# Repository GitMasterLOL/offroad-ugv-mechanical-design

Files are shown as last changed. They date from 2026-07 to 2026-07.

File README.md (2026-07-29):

# offroad-ugv-mechanical-design
My work as Mechatronics Intern at Vrishchik Technologies

---
## What this is

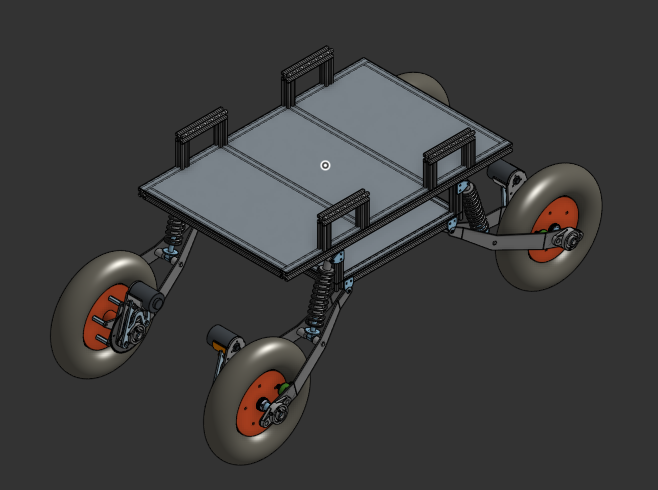
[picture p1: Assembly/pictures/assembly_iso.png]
assembly isometric view


This is a four wheeled trailing arm UGV designed for offroad logistics, developed at Vrishchik Technologies LLP. This repository is the **mechanical design report** containing CAD exports, renders, and drawings.

🔗 **[OnShape document link](https://cad.onshape.com/documents/ce47fbc74609b5a048dd3107/w/da249aea21ef6462a706381d/e/cdb04b3c972b51afe68cf9e2)**

---
## My role

As the Mechatronics Intern on this project, I worked on:
- Chassis load analysis, material selection, geometry analysis, design, structural analysis, and manufacturing 
- Trailing arm suspension kinematics, bearing selection, coilover sizing, design, and manufacturing
- Axle load case definition, stress analysis, material selection
- Evaluating chain drive sprocket mounting methods for manufacturability
- Chassis and mount design for onboard power and electronics

---
## Skills & tools demonstrated

- **CAD:** OnShape (parametric assemblies, dimensioned drawings for fabrication)
- **Suspension kinematics:** motion ratio calculation and tuning to hit a target wheel travel
- **Structural analysis:** stress and fatigue factor-of-safety calculation for axle sizing
- **DFM:** parts designed for minimal manufacturing complexity and cost
- **Manufacturing-aware design:** parts designed across 3D printing, CNC, laser cutting, and metal sheet bending

---
## Design highlights

**Chassis:** Aluminium T-Slot extrusions for weight management and rigidity (against bending and compression)

**Trailing arm suspension:** UCF205 pillow block bearings, ATV coilover shocks, ~200mm wheel travel

**Rear axle:** 304 stainless steel, fatigue FoS ≈ 2.4

---
## Repository map

```
TRAKR-rover/
├── README.md               ← you are here
├── Assembly/
│   ├── 3D_files/                Files of 3D printed components
│   ├── final_assembly.step              
│   ├── final_assembly.stl                
│   └── pictures/                 Pictures of assemblies and certain important components
└── drawings/                    dimensioned PDFs for anything fabricated
```

---
## Key specifications

| Parameter | Value |
|---|---|
| Overall dimensions (L×W×H) | 1m x 0.6m x 0.5m |
| Mass (as designed) | 100kg |
| Payload capacity | 100-120kg |
| Ground clearance | 300mm |
| Max traversable slope | 30 degrees |
| Wheel diameter | 14.5" |
| Primary materials | Aluminium, Mild steel |

---
## Fabrication

**Processes used:** 3D printing / CNC / laser cutting / sheet metal bending

**What has been completed:**
	- Chassis frame
	- First version of trailing arm suspension

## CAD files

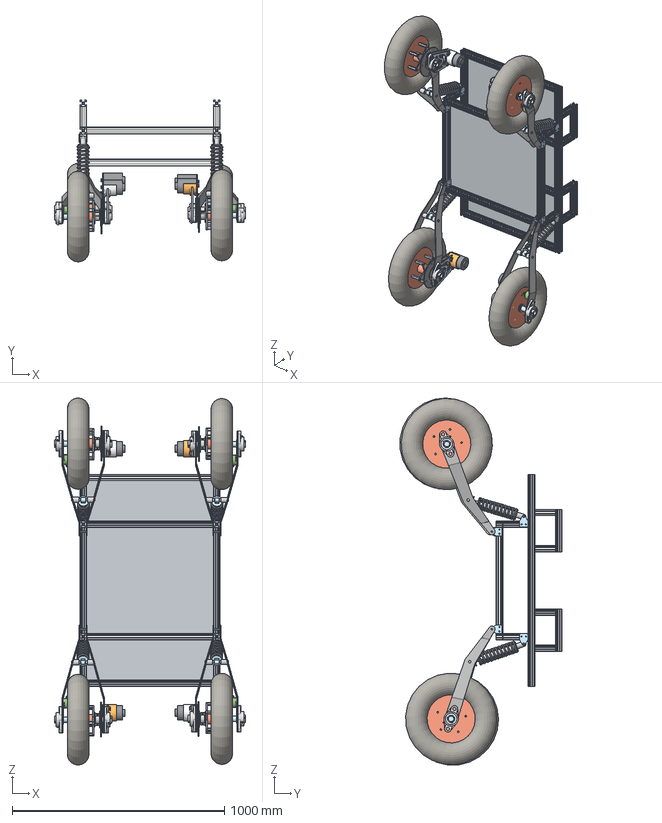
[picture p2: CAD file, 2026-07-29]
Assembly/final_assembly.step
902.4 x 763.2 x 1730.9 mm
shock pivot x 16
sheet x 2
mount x 4
GT2 60T x 4
motor x 4
trailing arm v2 left x 4
motor mount back plate x 4
shock to arm x 8
UCFL205J x 8
motor mount face plate x 4
trailing arm v2 right x 4
encoder x 4
motor mount base x 2
GT2 16T x 4
sprocket flange x 4
sprocket plate x 4
sprocket x 4
piston x 4
spring x 4
case x 4
spacer x 20
spider plate x 4
wheel x 4
spider collar 2 x 4
spider collar 1 x 4
rim x 4
motor mount base-Mirrored x 2

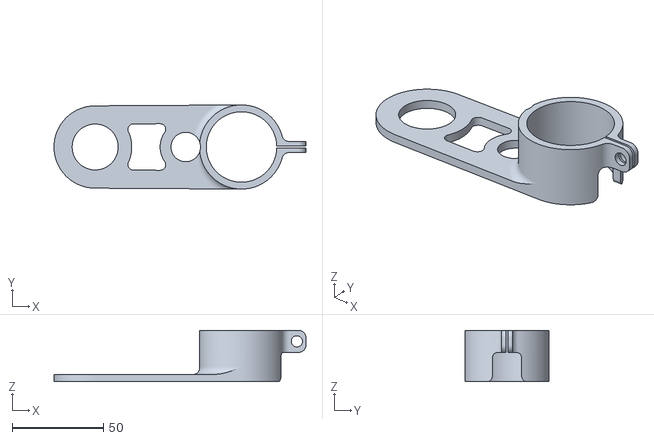
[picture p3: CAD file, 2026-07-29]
Assembly/3D_files/encoder mount.stl
137.7 x 46.0 x 28.0

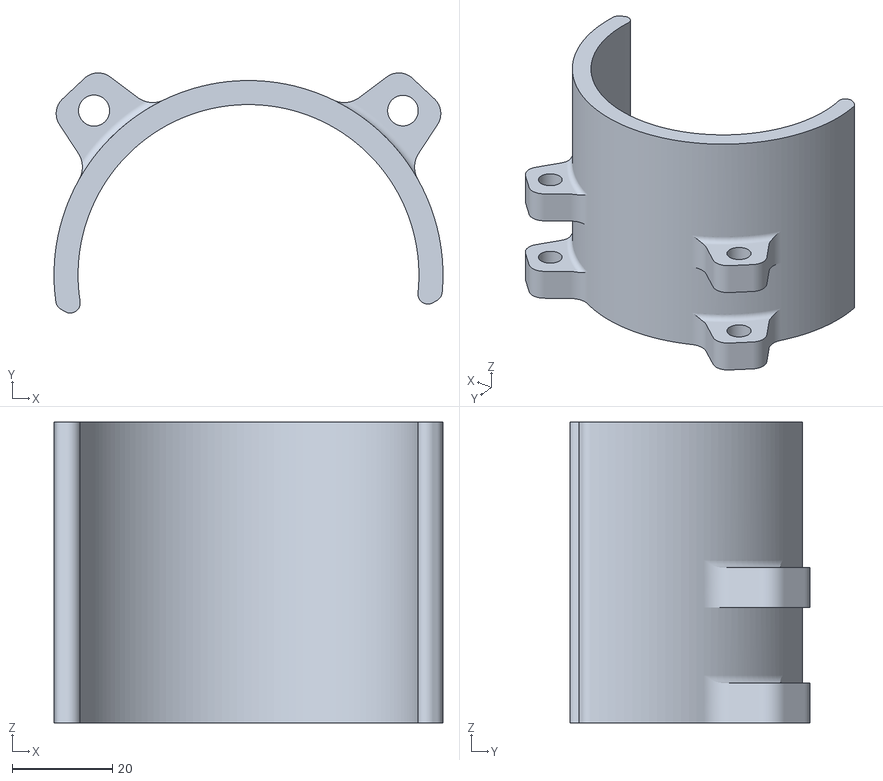
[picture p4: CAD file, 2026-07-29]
Assembly/3D_files/motor_mount/motor mount base.stl
77.6 x 47.9 x 60.0

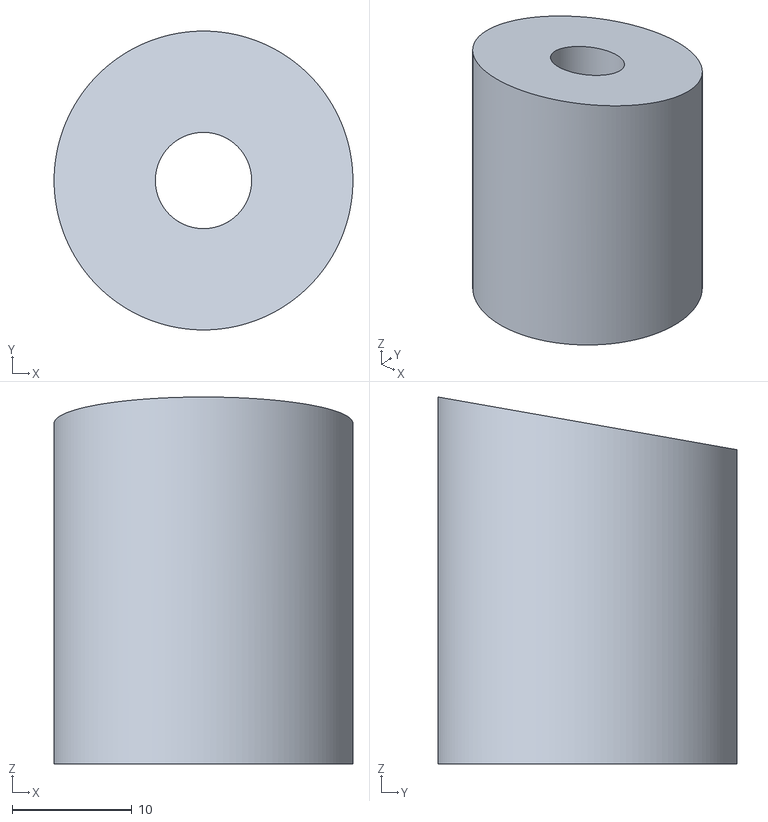
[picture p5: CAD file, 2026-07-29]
Assembly/3D_files/spacers/shock to arm v2.stl
25.0 x 25.0 x 30.7

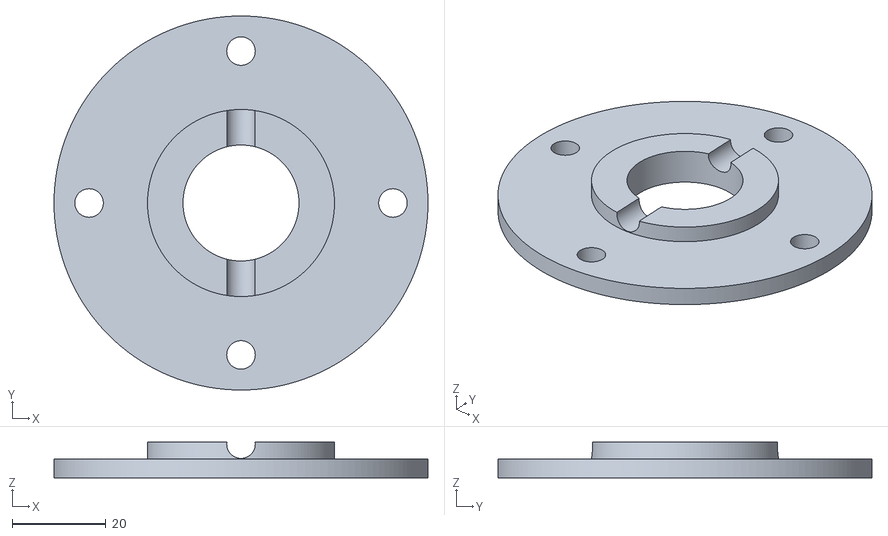
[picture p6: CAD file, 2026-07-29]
Assembly/3D_files/sprocket mount/sprocket mount - sprocket flange.stl
80.0 x 80.0 x 7.60

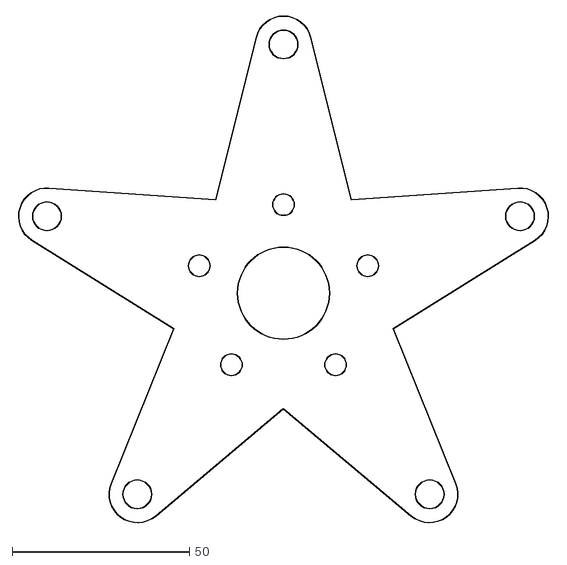
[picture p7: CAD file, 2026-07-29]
drawings/spider plate.dxf
151.1 x 143.7

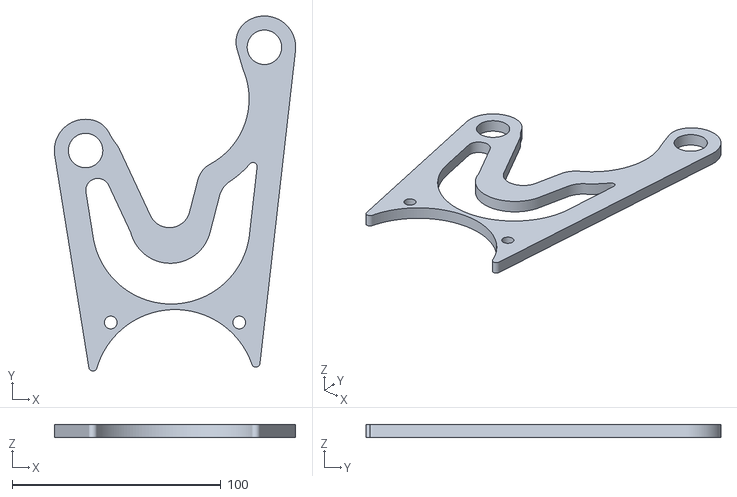
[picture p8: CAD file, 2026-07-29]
Assembly/3D_files/motor_mount/motor mount v2 - motor mount back plate.stl
115.7 x 170.2 x 6.00

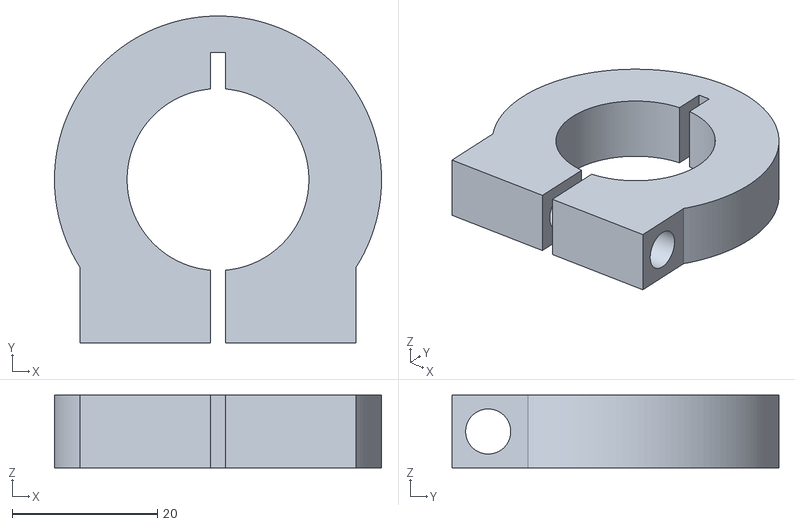
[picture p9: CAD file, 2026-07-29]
Assembly/3D_files/shaft_locker.stl
45.0 x 45.0 x 10.0

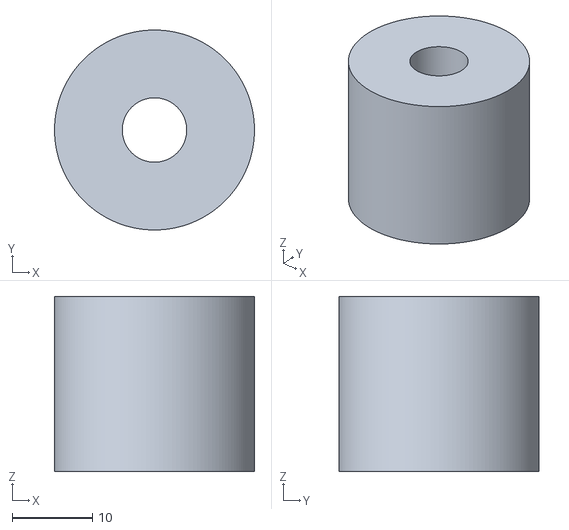
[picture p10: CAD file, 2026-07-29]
Assembly/3D_files/spacers/arm pivot.stl
25.0 x 25.0 x 21.9

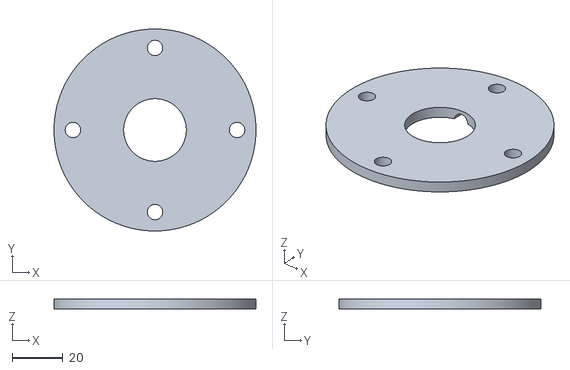
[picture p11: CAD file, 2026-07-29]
Assembly/3D_files/sprocket mount/sprocket mount - sprocket plate.stl
80.0 x 80.0 x 4.00

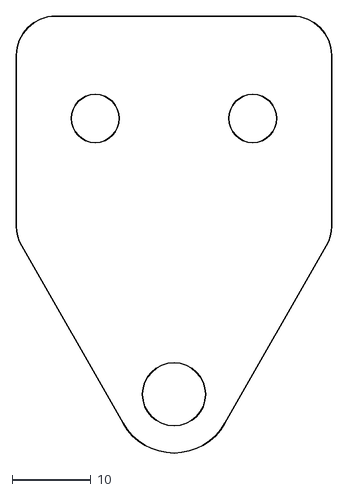
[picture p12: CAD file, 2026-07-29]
drawings/shock pivot.dxf
40.0 x 55.4

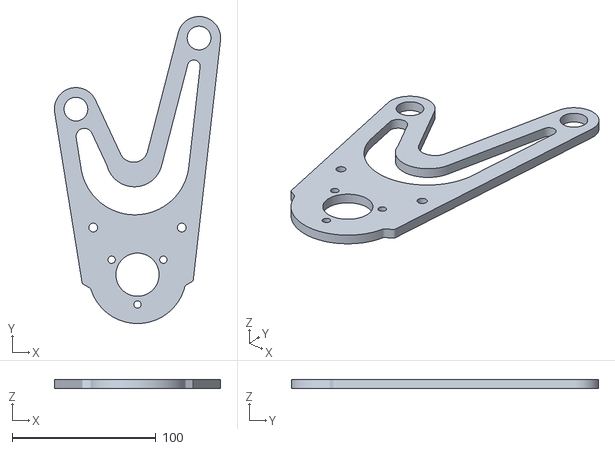
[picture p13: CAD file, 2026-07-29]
Assembly/3D_files/motor_mount/motor mount v2 - motor mount face plate.stl
115.7 x 213.7 x 6.00

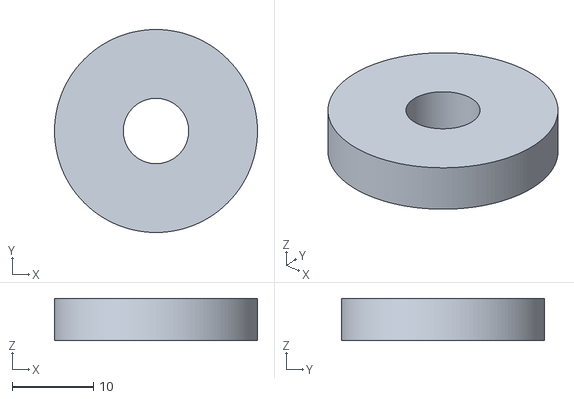
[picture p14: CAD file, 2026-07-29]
Assembly/3D_files/spacers/shock top v2.stl
25.0 x 25.0 x 5.20

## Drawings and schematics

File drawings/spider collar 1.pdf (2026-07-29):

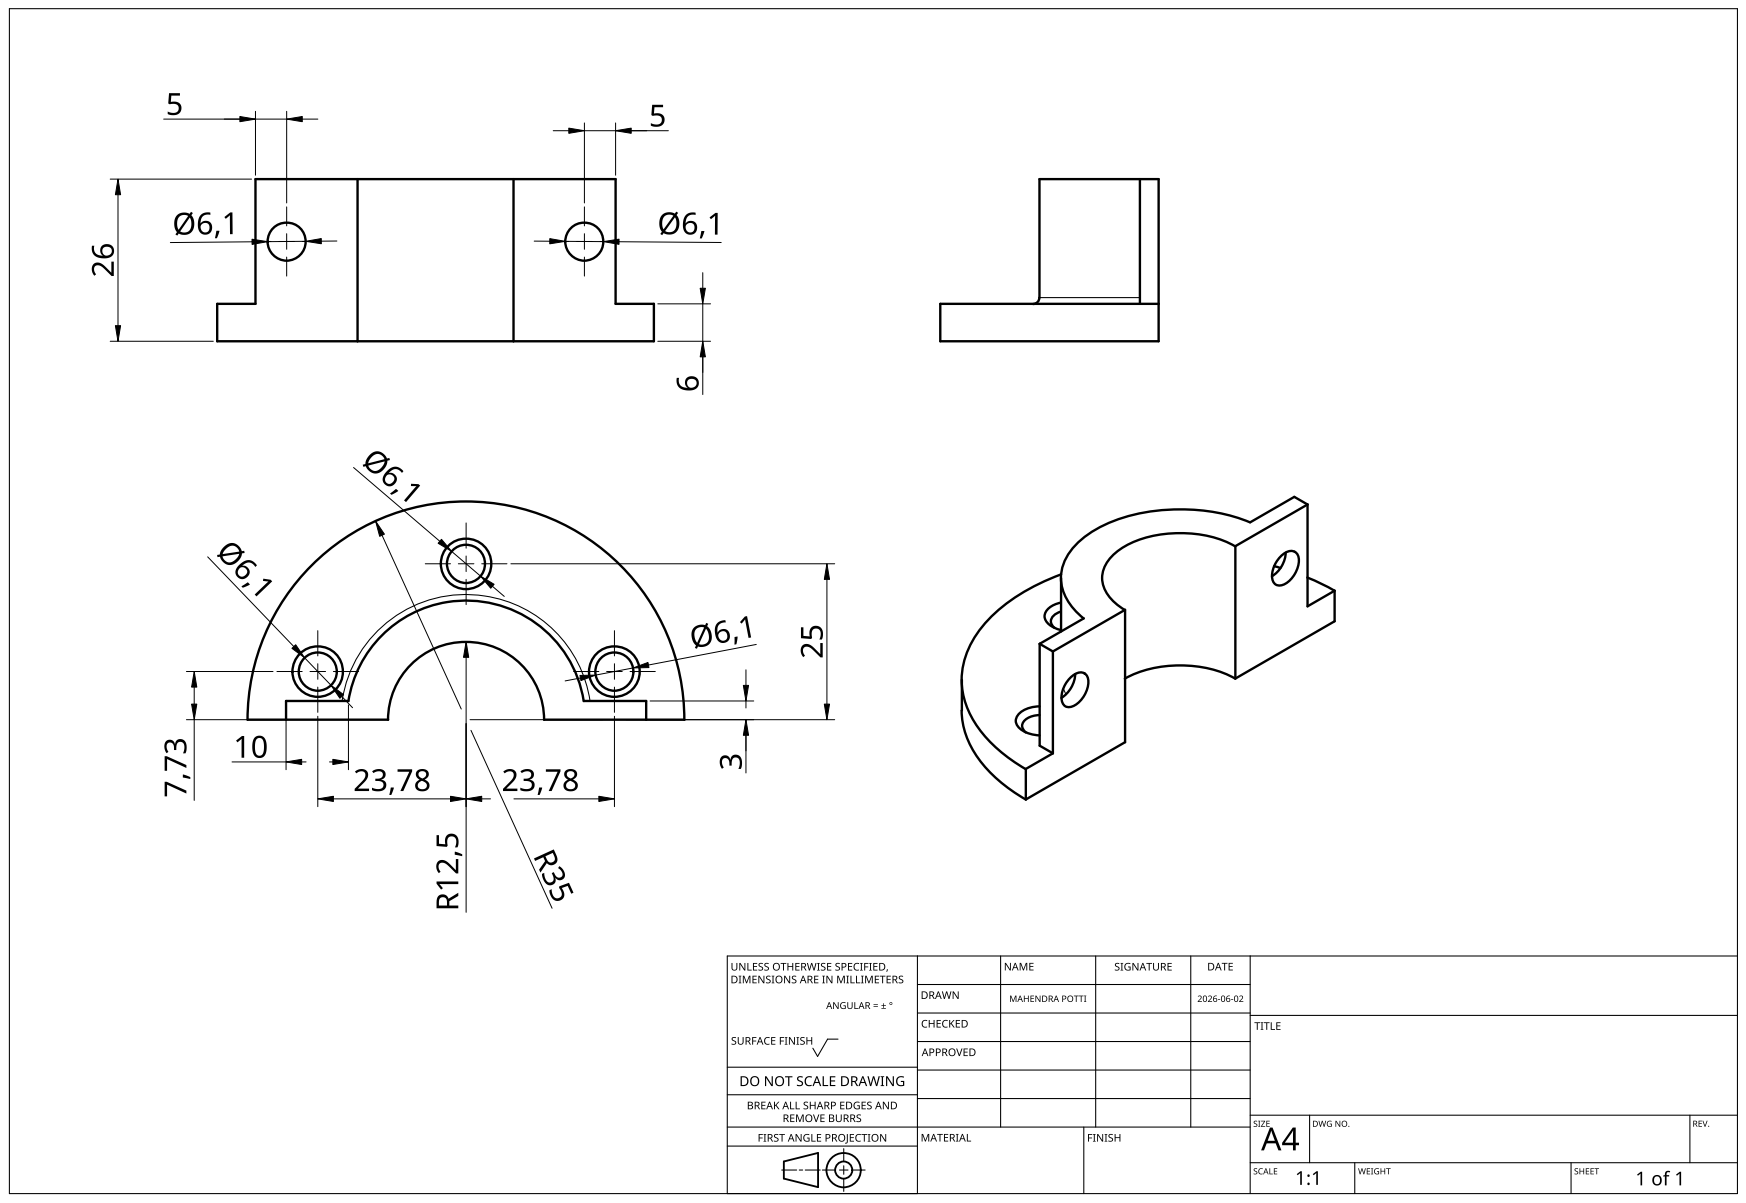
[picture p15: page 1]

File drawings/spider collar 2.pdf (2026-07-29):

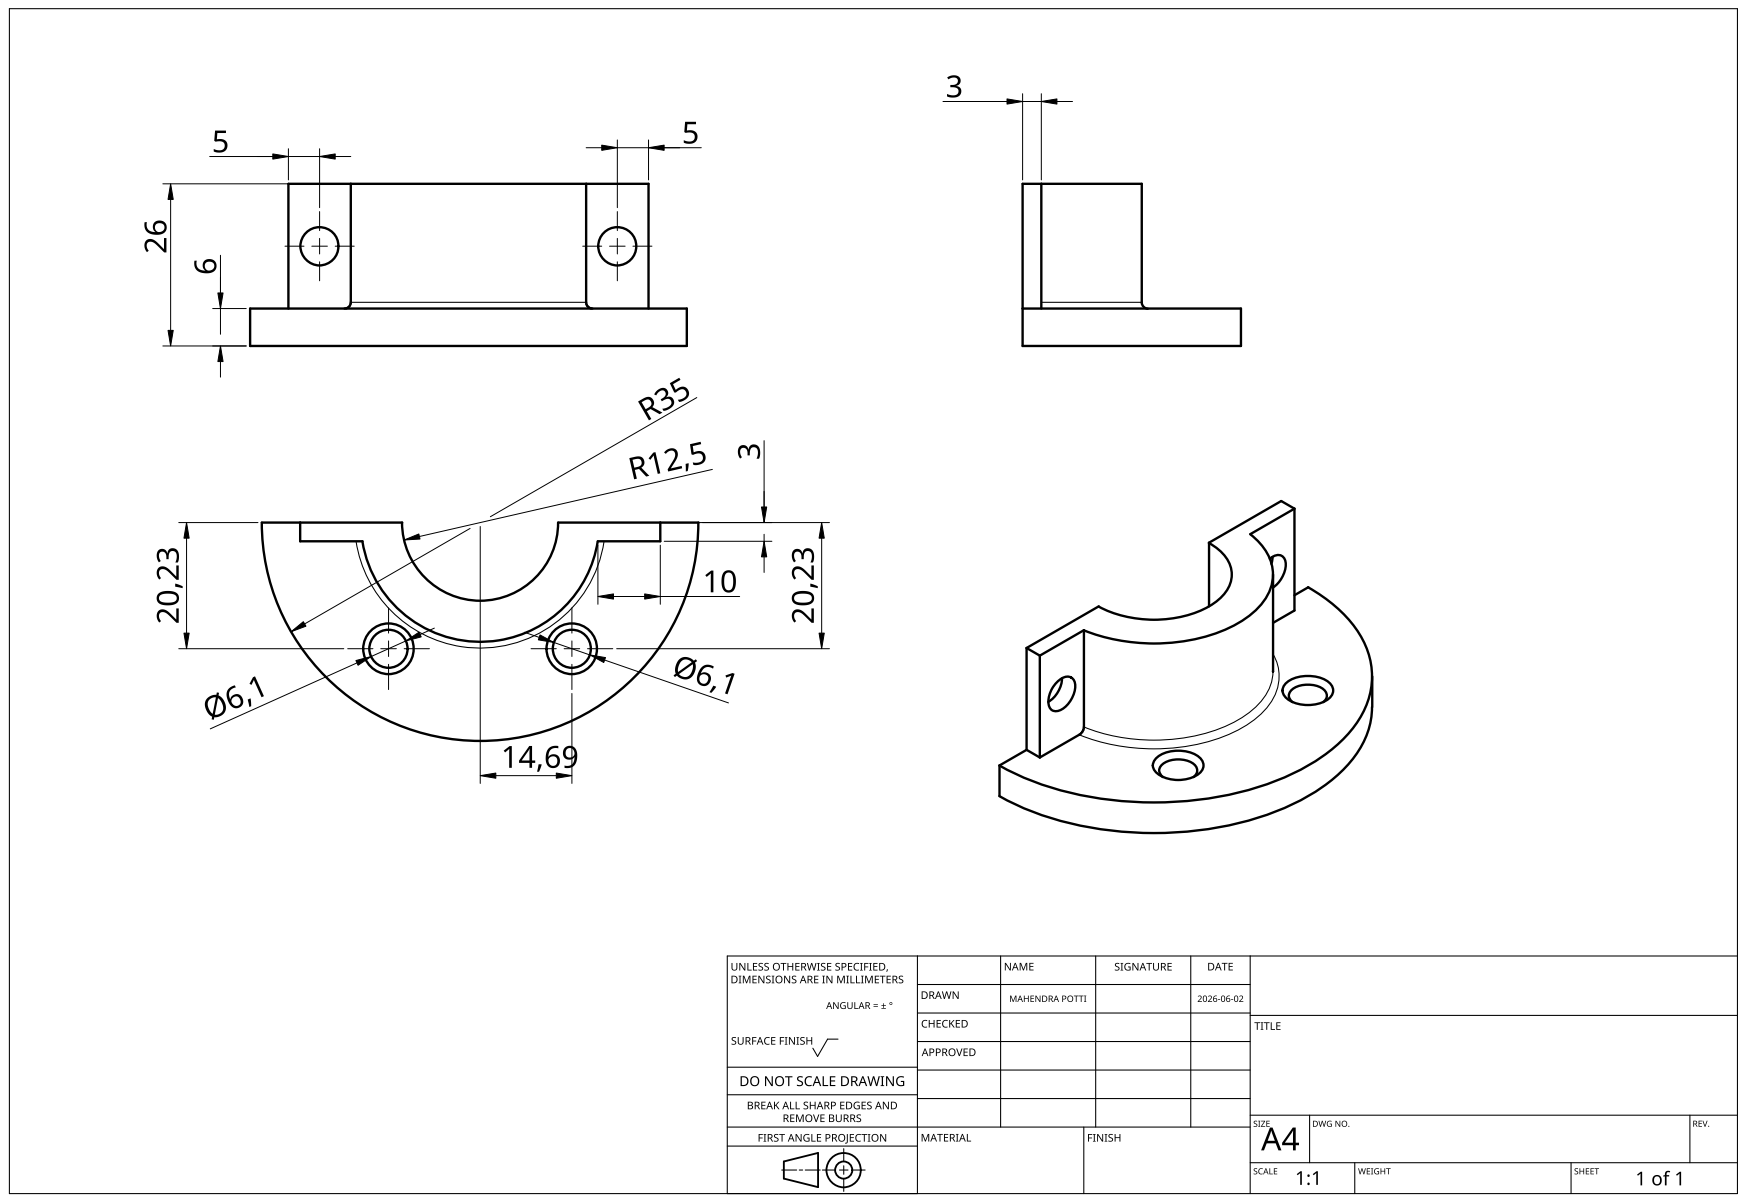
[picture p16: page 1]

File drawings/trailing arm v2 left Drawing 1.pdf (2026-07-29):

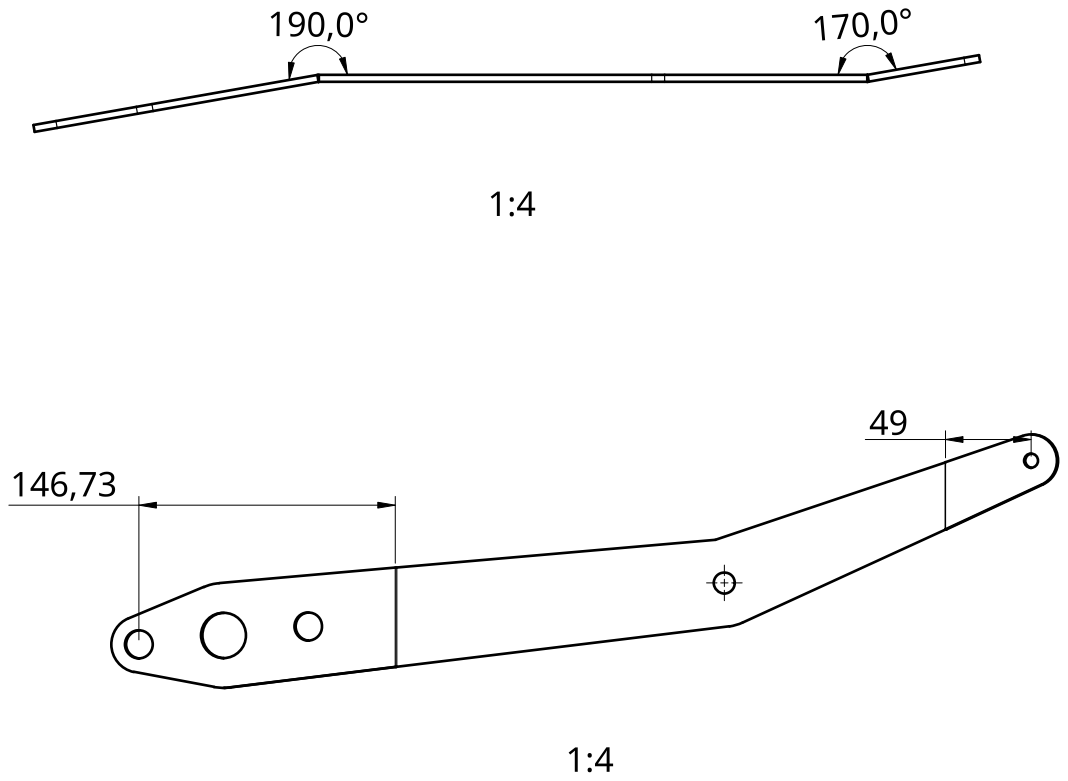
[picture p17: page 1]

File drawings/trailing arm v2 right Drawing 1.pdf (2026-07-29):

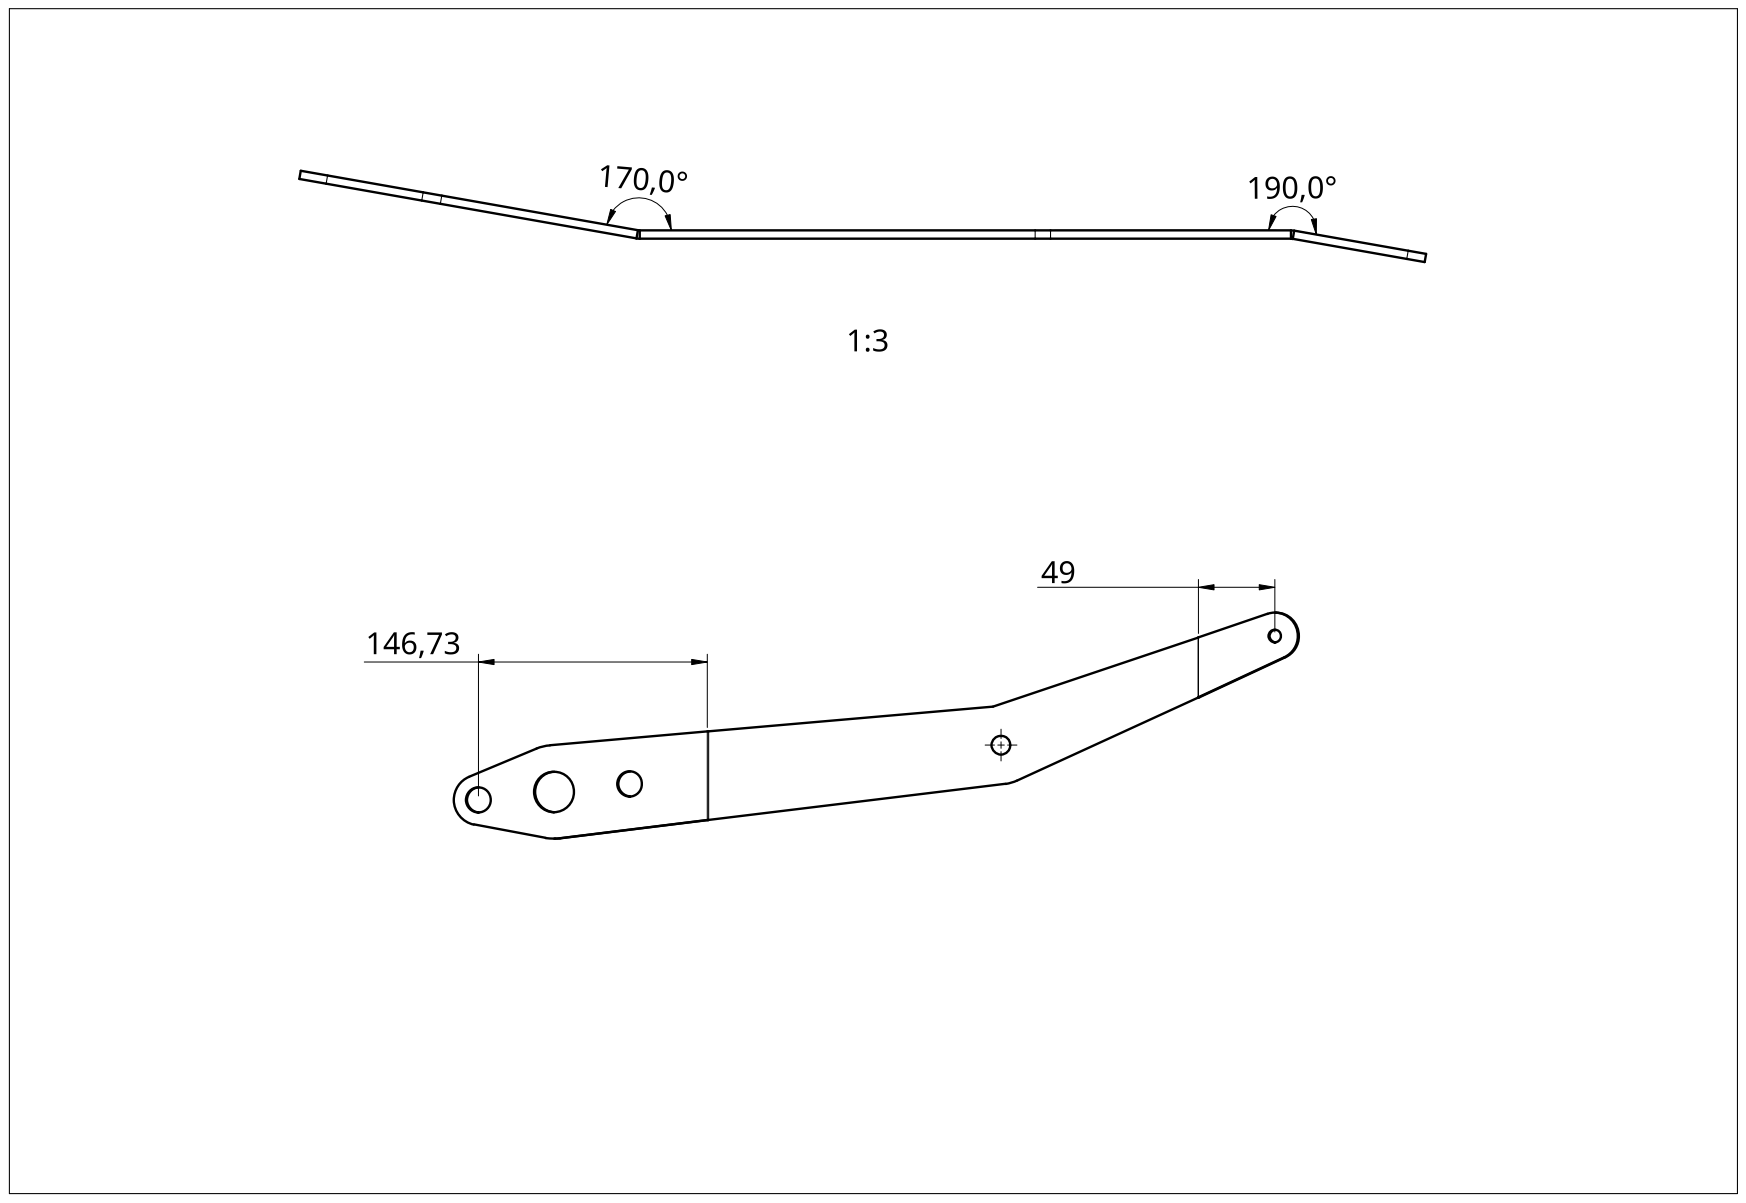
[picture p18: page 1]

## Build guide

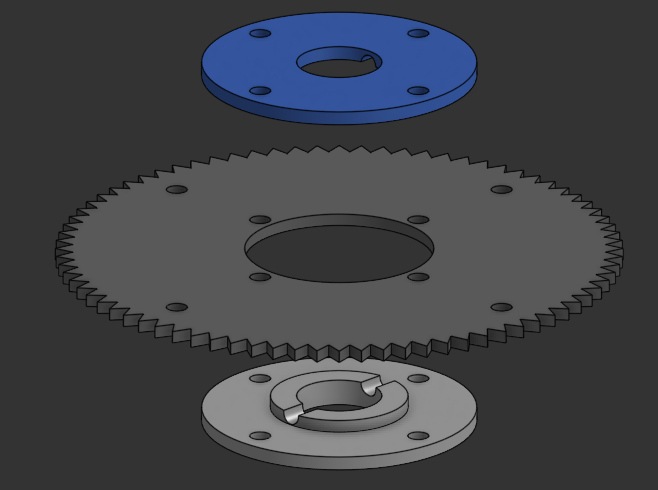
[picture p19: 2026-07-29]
Assembly/pictures/shock_assm_explosion.png

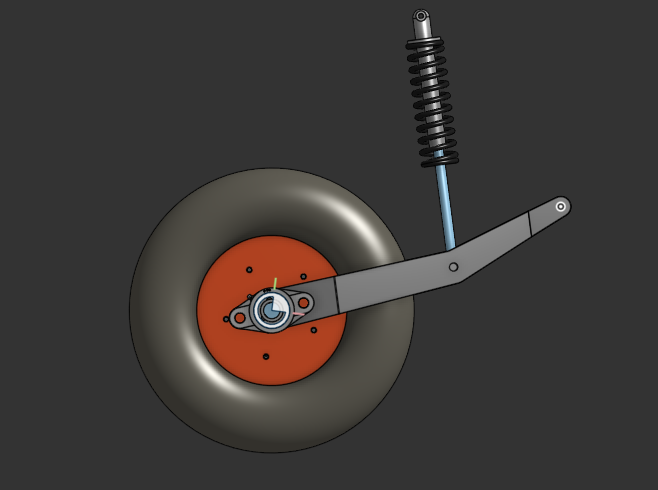
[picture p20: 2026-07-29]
Assembly/pictures/one_corner_2.png

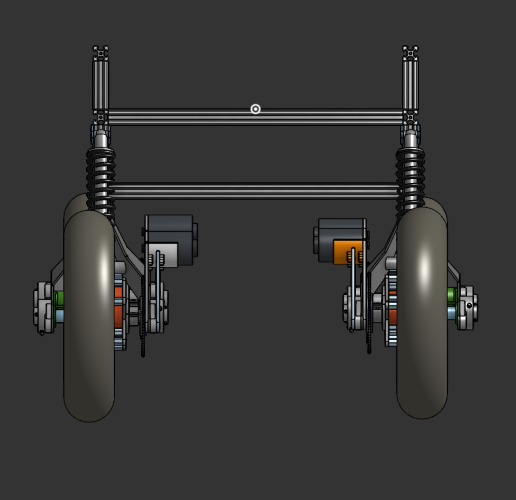
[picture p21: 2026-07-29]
Assembly/pictures/assembly_front.png

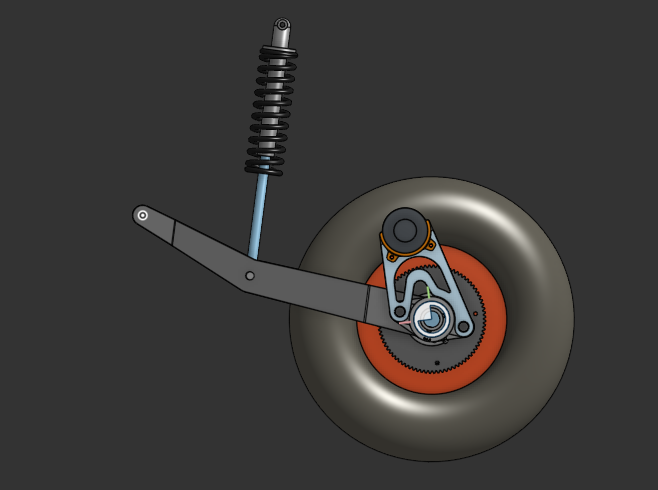
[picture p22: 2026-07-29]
Assembly/pictures/one_corner_1.png

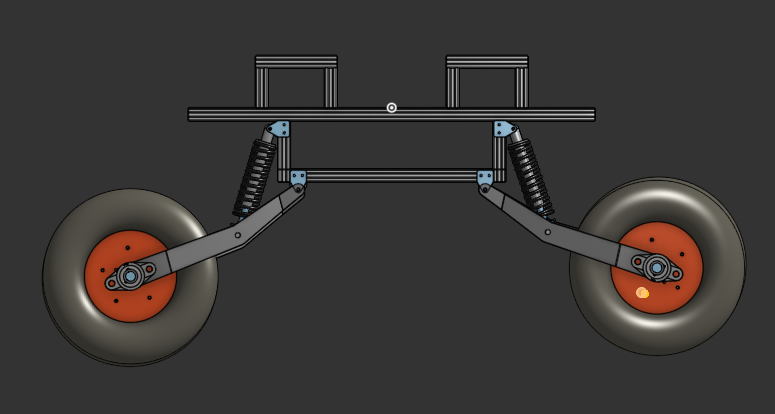
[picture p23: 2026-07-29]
Assembly/pictures/assembly_side.png
